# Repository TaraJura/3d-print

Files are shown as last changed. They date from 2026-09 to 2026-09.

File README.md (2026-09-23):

# 3D tisk a elektronika

Osobní projekt Jiřího Nováka: parametrické modely, 3D tisk, elektronika a zkušenosti ze sestavování. Znalosti i nové modely patří sem, aby šlo v další úloze pokračovat bez opakovaného vysvětlování. Nejde o firemní TechTools projekt ani o TechTools Brain.

Jiří popíše požadovaný díl nebo změnu běžným jazykem. Agent připraví model programově ve FreeCADu a Jiří si výsledek prohlédne.

[Sekce elektroniky](elektronika/README.md) je určená také pro všechny další osobní elektronické projekty bez vazby na 3D tisk. Nový projekt patří do `elektronika/<nazev>/` a do tamního indexu; jeho úplný propojený kontext zůstává v tomto repozitáři. Firmware existujícího autíčka má výjimku kvůli zachování původní cesty u modelu.

## Kde začít

- [AGENTS.md](AGENTS.md) — pravidla pro další práci agentů.
- [Tiskárna](docs/tiskarna.md) — Anycubic Kobra X, ověřené údaje a neznámé.
- [Software](docs/software.md) — FreeCAD, Anycubic Slicer Next a spuštění makra.
- [Sklad tiskových materiálů a profily](docs/materialy.md) — evidence filamentů, známé zůstatky, defaulty a doporučení.
- [Postup práce](docs/workflow.md) — od zadání přes model a slicer k vyhodnocení tisku.
- [Deník tisků](docs/denik-tisku.md) — skutečně hlášený průběh a výsledky.
- [Modely](models/README.md) — přehled všech dílů a jejich zdrojů.
- [Elektronika](elektronika/README.md) — zapojení, zkoušky a aktuální stav projektů.
- [Sklad elektroniky a vybavení](elektronika/vybaveni.md) — kanonický inventář včetně fyzicky převzaté sady kondenzátorů.

## Aktuální stav k 19. 9. 2026

**V3 25:1 po první a druhé várce, 20. 9. 2026:** připravená je [jedna kombinovaná podložka s26 kusy](models/auticko-silovy-prevod-25/rozlozeni/kombinovana-03-2026-09-20/README.md):13 dosud netištěných z původní03,7 náhrad první várky a6 druhé. Čepy i osa jsou nastojato; proces obsahuje ověřené skutečné podpory plošiny, osy a obou těhlic. **Použít tuto jednu podložku místo samostatné03 a sedmidílného dotisku.** Odhad19h37min /120,09g. Rám, víko objímky a úplnost obou motorových klínků čekají na upřesnění;26 není potvrzení kompletního použitelného inventáře. Tisk ani montáž této kombinace nejsou fyzicky ověřené.

**Doplnění 20. 9. 2026:** [celá V3 25:1 po revizi fitů](models/auticko-silovy-prevod-25/README.md) je připravená jako tiskový prototyp: 66 kusů na [třech podložkách 26 / 27 / 13](models/auticko-silovy-prevod-25/rozlozeni/README.md), včetně všech čtyř kol. Zachovává původní 20° ozubení a nové kluzné otvory 8,6 / 12,6; pevné spoje jsou oddělené podle funkce. Nominální CAD a exporty jsou ověřené pro tuto revizi; celý konzervativní radiální scénář zůstává nepokrytý, fyzická montáž a jízda neověřené. Další vzorky nejsou podmínkou předání. Soubory se předávají výhradně v projektu; na plochu se nic dalšího nekopíruje.

**Nahrané couvání, 23. 9. 2026:** verze `v3-reverse-v1` přidává **Držet pro couvání / ArrowDown**, opačnou polaritu motoru při stejném PWM 128/255 a zachovává servo 1275 / 1575 / 1875 µs při 50 Hz. **Je nahraná a potvrzená třemi pasivními výpisy; uživatel následně obecně potvrdil funkčnost („Hele, všechno to funguje“).** Překlad a úplné offline regrese prošly. Konflikt vpřed/vzad zastaví obě ovládání. Při odmítnuté rychlé změně směru je nutné pustit všechny ovladače a znovu stisknout; samotný čas ani opakovaný HOLD pohon neobnoví. Před opačným směrem je požadováno nejméně 250 ms skutečně vypnutého výstupu, což není měření zastavení motoru. Piny ani směr kol při couvání se nepřepojují/neobracejí. Upload **86 716 B / 22 stran / exit 0** a tři pasivní výpisy potvrdily novou verzi a klidové výstupy. Čítače zařízení byly stabilní **HTTP=29 / closed=29**; původ dřívějších požadavků není určený. Agent odeslal 0 sériových dat, 0 HTTP a 0 pohybových povelů; port je zavřený a volný. **Po následné zkoušce uživatel obecně potvrdil funkčnost; agent pohyb ani elektrické měření PWM neprováděl.** [Nová evidence uploadu](models/jednoduche-auticko/firmware/prvni-motor/evidence/2026-09-23-v3-reverse-v1-upload/README.md). Uživatel nově potvrdil servo odpojené v dotazu zahrnujícím UNO na USB a motor bez napájení. [První fyzická zkouška](elektronika/auticko/rizeni-v3.md#příští-zkouška-couvání--zatím-neprovedená) má nyní obecné uživatelské potvrzení funkčnosti.

**Historická kalibrace V3, 22. 9. 2026:** Dříve byl nahraný **`v3-steering-v4`: střed 1575 µs, zachované ±300 µs a 50 Hz (1275 / 1575 / 1875 µs)**. Upload **84 948 B / 21 stran / exit 0** a tři pasivní USB výpisy potvrdily novou verzi, klid motoru, `steeringUs=neutralUs=1575` a `rangeUs=300`. **Uživatel následně s připojeným táhlem a povelem Rovně potvrdil správnou neutrální polohu kol: „Super, takhle to je perfektní“.** Jde přímo o +50 µs od v3 ve směru Doprava, bez mezikroku 1550 µs. Uživatel na v3 s připojeným táhlem a povelem Rovně stále hlásil kola mírně doleva; první +25µs trim byl podle něj skoro neznatelný. Potvrzení se týká neutrální polohy při krátké zkoušce s koly nad stolem a motorem bez napájení; úhel, všechny dorazy, dlouhodobý provoz ani jízda nejsou ověřené. Pro upload v4 uživatel nově odpověděl „Ano“ na dotaz zahrnující odpojení servo plusu, ponechání UNO na USB a motor bez napájení. Táhlo zůstalo při závěrečné zkoušce připojené. Doporučené odpojení serva po tomto úspěchu tehdy nepotvrdil; nové potvrzení odpojení přišlo před uploadem couvání uvedeným výše. Akceptace neutrálu v4 se nepřenáší na nový hash. Potvrzený pohyb volného serva v2 oběma směry zůstává samostatným výsledkem. [Přesná chronologie](elektronika/auticko/kontrolni-zapojeni.md#hlasova-zkouska-22-9-2026), [řízení V3](elektronika/auticko/rizeni-v3.md) a [firmware s evidencí](models/jednoduche-auticko/firmware/prvni-motor/README.md) rozlišují verze, upload a fyzické výsledky. Přímý 6,35V zdroj zůstává rizikovým pokusem nad uváděnými 4,8–6 V, bez hotového regulátoru.

Tiskárna je **Anycubic Kobra X s tryskou 0,4 mm**. K dispozici je bílý a černý **Alzament PLA Basic 1,75 mm**. Uživatel potvrdil spuštění FreeCADu a Anycubic Slicer Next na Ubuntu 26.04.1 LTS.

První model je [polička na zárubeň 90 × 50 mm](models/policka-na-zaruben/README.md). Její geometrie byla ověřena a uživatel model otevřel i importoval do sliceru. Uživatel oznámil zahájení prvního tisku; **fyzický výsledek ani první vrstva zatím nejsou potvrzené**. U zkontrolovaného lokálního G-code není jednoznačně doloženo, že jde právě o úlohu běžící na tiskárně. Podrobnosti jsou v [deníku](docs/denik-tisku.md).

Další model je [jednoduché autíčko s jedním motorem](models/jednoduche-auticko/README.md): čtyři kola, společná zadní náprava a ozubený převod. První FCStd a jednotlivé STL jsou vytvořené a geometricky zkontrolované. **Uživatel na vytištěném vzorku zvolil otvor 2,2 mm a následně potvrdil dobré nasazení hotového [pastorku](models/jednoduche-auticko/stl/pastorek.stl).** Tisk zbývajících 13 kusů zadal s odhadem sliceru 3 h 15 min; dokončení zatím nepotvrdil. **První sekundový rozběh samostatného motoru tlačítkem z telefonu přes UNO R4 WiFi a L293D uživatel potvrdil.** [Záznam sestavování, zapojení a posledního stavu](elektronika/auticko/prvni-stolni-test.md) obsahuje i provizorní napájení a otevřené body. Fyzická montáž podvozku a jízda ještě ověřené nejsou.

Autíčko nově doplňuje **[snímatelná plošina s užitnou plochou 170 × 60 mm](models/jednoduche-auticko/strecha.md)**. Nasazuje se na čtyři existující výstupky u kol; původní rám se nemusí tisknout znovu. **Uživatel potvrdil dokončení tisku a nasazení.** Správný dosed, provozní vůle, nosnost a stabilita nejsou potvrzené.

[Elektronika autíčka](elektronika/auticko/README.md) soustřeďuje zapojení a historii motorových zkoušek. **Historická verze `hold-to-run-v2` byla přeložená, otestovaná a nahraná 19. 9.; dnešní upload V3 je uveden výše.** Předchozí požadavek na návrat k sekundovému pulzu uživatel odvolal před uploadem. [Firmwarový návod](models/jednoduche-auticko/firmware/prvni-motor/README.md) uvádí skutečný stav testů a nahrání. [Záznam potíží](elektronika/auticko/potize-po-montazi.md) odlišuje těžký rozjezd již na starém programu od přerušování při skutečném držení. Po návratu uživatel obnovil stránku a opakovaně potvrdil funkční držení, puštění a další stisk („Jo, funguje to, perfektní“). Jde o jeho fyzickou zkoušku v2, nikoli měření doběhu či zatížení. Nákup nářadí a baterií i použití silikonového oleje jsou v [inventáři](elektronika/vybaveni.md); vlastnictví neznamená potvrzené zapojení.

Dokončený je nový model [samostatného autíčka s převodovkou 12:1](models/auticko-s-prevodovkou/README.md), koly Ø80 a užitnou plošinou 170 × 60 mm pro stávající elektroniku. Vůči původnímu převodu 3:1 s koly Ø60 je ideální tažná síla 3× a rychlost 1/3, před ztrátami. [Balíček pro tisk](models/auticko-s-prevodovkou/tiskovy-balicek.zip) obsahuje 20 kusů ze 13 typů STL, každý soubor tisknout jednou. Hotové jsou parametrický FCStd, náhledy a montážní návod; prošly kontroly těles, STL, kolizí, soukolí i montážních vůlí. Původní modelové soubory zůstaly beze změny. Jiří nyní při fyzické zkoušce V2 hlásí opakované zasekávání a podezření na nesprávnou rozpěrku; příčina ani výsledek přestavby nejsou potvrzené. [Audit a návrh revize převodovky](models/auticko-s-prevodovkou/revize-prevodovky.md) ukázal potřebu změnit vedení os, axiální stohy a šířku záběru. Uživatel zvolil pouze tištěné mechanické díly. Samostatná silnější revize 25:1 je popsaná níže; původní CAD i firmware zůstávají zachované.

**Dokončená je třetí samostatná [varianta s předním zatáčením přes SG90](models/auticko-se-zatacenim/README.md).** Má převodovku 12:1, plošinu 170 × 60 mm a kola Ø76 × 12 mm se skutečným tištěným dezénem. CAD, exporty a geometrické kontroly jsou hotové; kompletní balíček obsahuje 33 kusů, přestavba z V2 vyžaduje 22 kusů při převzetí 11 původních. Pro Kobra X je připravené [rozložení na dvě podložky](models/auticko-se-zatacenim/rozlozeni/README.md), 31 + 2 kusy. Fyzický tisk, montáž, síla řízení a přilnavost zůstávají neověřené. Potvrzené servo a měření účinného poloměru páčky 15 mm jsou v [inventáři](elektronika/vybaveni.md). Oba předchozí modely i firmware zůstávají zachované; elektronika zatáčení je další etapa.

**Aktuální [V3 25:1 s řízením SG90](models/auticko-silovy-prevod-25/README.md)** má 34 typů / 66 tištěných kusů a samostatně archivovanou předkalibrační variantu. Kompletní ZIP a tři 3MF zahrnují čtyři kola a všechny opakované díly; počty se už nenásobí. Poslední 8mm pastorek zůstává v 12mm věnci při kontrolovaných axiálních posuvech s rezervou 1,5 mm. Rozměry konkrétní páčky, fit celé sestavy a jízda teprve čekají na fyzické ověření. Původní CAD a firmware jsou zachované.

## Jak zapisovat poznatky

U nového údaje uvést původ: zadání uživatele, fyzické měření, údaj výrobce, kontrola souboru, návrhová hodnota nebo doporučení. Zadané rozměry nejsou automaticky měřením skutečného předmětu. Doporučení není potvrzené nastavení a kontrola modelu není důkaz úspěšného výtisku.

Nové parametry a změny modelů zapisovat do příslušné složky modelu; elektroniku do `elektronika/<projekt>/`, elektronické vybavení do [inventáře](elektronika/vybaveni.md) a tiskové materiály do [skladu](docs/materialy.md). Po tisku doplnit deník podle skutečného výsledku. **Vytvoření STL, úspěšné řezání ani odeslání úlohy nestačí k označení tisku za úspěšný.** Upload programu sám není potvrzením fyzického výsledku.

## Projekt a Git

Aktuální místní checkout je `/home/novakj/3d-print`; osobní repozitář je [TaraJura/3d-print](https://github.com/TaraJura/3d-print). Git příkazy spouštět v tomto checkoutu: domovský adresář `/home/novakj` má vlastní, odlišný repozitář. Zdejší obsah se přípravou dokumentace automaticky necommituje ani nepublikuje.

Malé záměrné soubory FCStd, STL a PNG patří k modelu a jsou verzovatelné. Instalátory, runtime, přístupové údaje, cache a automatické zálohy do projektu nepatří. Původní kopie poličky v `Documents/3D-models` zůstala zachovaná kvůli otevřeným souborům; další práci ukládat sem.

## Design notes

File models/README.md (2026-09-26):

# Modely

Každý model má vlastní složku se zadáním, editovatelným zdrojem, STL, skutečným CAD náhledem a výsledky kontrol. Nové modely ukládat sem. Zapojení a elektronické zkoušky patří do [elektroniky](../elektronika/README.md); potvrzené součástky a pomůcky do [inventáře](../elektronika/vybaveni.md).

| Model | Obsah a stav |
|---|---|
| [Zaoblený kryt trubky digestoře](kryt-trubky-digestore/README.md) | Předběžný půlkruhový kryt 150 × 75 × 98 mm pro přibližnou trubku Ø130: FreeCAD, STL, skutečné náhledy a jedna nařezaná 3MF podložka pro Kobra X. Dosednutí, odstup od zdi, provozní teplota, vhodnost PLA a tisk čekají na fyzické ověření. |
| [Koupelnová přepážka B](koupelnova-prepazka/revize-03-575-zacvak/README.md) | Návrh k posouzení: 575 × max. 20 × cca 10 mm po montáži, 3 TPU díly 8 mm + lože 2 mm, mechanické zacvaknutí bez lepidla mezi díly. CAD, náhledy a oba experimentální TPU projekty ověřeny počítačově; fyzické zacvaknutí, přilnutí a těsnost neověřeny |
| [Polička na zárubeň](policka-na-zaruben/README.md) | Deska 90 × 50 mm; geometrie ověřena; uživatel zahájil první tisk, fyzický výsledek nepotvrzen |
| [Jednoduché autíčko](jednoduche-auticko/README.md) | Pastorek s CAD otvorem Ø 2,2 mm vytištěn a nasazení potvrzeno; tisk dalších 13 kusů zadán. [První sekundový stolní test motoru přes telefon](../elektronika/auticko/prvni-stolni-test.md) potvrzen uživatelem; montáž podvozku a jízda neověřeny |
| [Snímatelná plošina autíčka](jednoduche-auticko/strecha.md) | Jeden přídavný díl na existující výstupky, rovná užitná plocha 170 × 60 mm. Dokončení tisku potvrdil uživatel; fyzický fit a nosnost teprve čekají na ověření |
| [Robotická ruka na autíčko](roboticka-ruka/README.md) | První lehký prototyp s krokovým otáčením základny, ručně polohovatelným ramenem a otevřenou dvouprstou koncovkou; FreeCAD, STL, náhledy a dvě nastavené a místně nařezané 3MF podložky hotové. Fyzický tisk, fit a nosnost neověřené |
| [Držák toaletního papíru s čelním šuplíkem](drzak-toaletniho-papiru-s-prihradkou/README.md) | Vlastní parametrický návrh podle fotografie bez měřítka: pevný strop, volně výsuvný šuplík, dvě ramena, osa a zátka. CAD, STL a [dvě nastavené a místně nařezané 3MF podložky](drzak-toaletniho-papiru-s-prihradkou/rozlozeni/README.md) pro Kobra X; tisk, hladký chod a kotvení neověřené. |
| [Nové autíčko s převodovkou 12:1](auticko-s-prevodovkou/README.md) | Samostatný nový prototyp s koly Ø80 a užitnou plošinou 170 × 60 mm. FCStd, náhledy, návod a [ZIP 20 kusů](auticko-s-prevodovkou/tiskovy-balicek.zip) hotové; geometrické kontroly prošly. Nově uživatel hlásí fyzické zasekávání; [audit a návrh revize](auticko-s-prevodovkou/revize-prevodovky.md) hotový, příčina nepotvrzená a původní geometrie zachovaná |
| [Autíčko s předním zatáčením](auticko-se-zatacenim/README.md) | Třetí samostatný CAD prototyp: pohon 12:1, plošina 170 × 60 mm, SG90 a kola Ø76 × 12 mm s dezénem. Kontroly, FCStd, náhledy a balíčky 33 / 22 kusů hotové. [Rozložené 3MF pro Kobra X](auticko-se-zatacenim/rozlozeni/README.md): 31 + 2 kusy. Tisk, fyzická montáž a řízení zatím nepotvrzené |
| [Revidovaná V3 s převodem 25:1](auticko-silovy-prevod-25/README.md) | **Tiskový prototyp po revizi 20. 9.: 34 typů / 66 kusů, čtyři kola, [tři 3MF 26 + 27 + 13](auticko-silovy-prevod-25/rozlozeni/README.md).** Původní 20° ozubení, kluzné otvory 8,6 / 12,6 a samostatné pevné spoje. Nominální CAD a exporty ověřené; plný konzervativní radiální scénář neprošel, skutečný fit a jízda neověřené. Další vzorky nejsou podmínkou předání. |

Společný [postup práce](../docs/workflow.md) a [deník tisků](../docs/denik-tisku.md) doplňují konkrétní poznámky modelu.

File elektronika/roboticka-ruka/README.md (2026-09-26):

# Robotická ruka na autíčku — elektronika

Projekt založen 23. 9. 2026 pro první lehký tisknutelný prototyp paže na jednoduchém kolovém autíčku. Mechanický model a tiskové soubory jsou v [modelu robotické ruky](../../models/roboticka-ruka/README.md); stav zásob je pouze v [kanonickém inventáři](../vybaveni.md).

## Aktuální stav

- Jiří potvrdil dostupný krokový motor se štítkem hlasem čteným jako „StepMotor 28BY…-48, 5 V DC“. Přesné znaky označení, počet kusů, rozměry a funkce jeho motoru zatím nejsou fyzicky ověřené.
- První návrh využije krokový motor jen pro pomalé otáčení základny kolem svislé osy. Rameno a loket zůstanou ručně polohovatelné a otevřená dvouprstá koncovka nebude zatím aktivně svírat.
- Servo SG90 je v dosavadní evidenci určené pro řízení autíčka; s volným kusem pro paži se nepočítá.
- Pro tuto paži zatím není potvrzené elektrické zapojení, zdroj napájení, přiřazení pinů, firmware, nahrání programu ani fyzická zkouška pohybu.

## Podklady pro navazující zapojení

[LaskaKit uvádí pro běžný 28BYJ-48](https://www.laskakit.cz/krokovy-motor-28byj-48/) napájení 5 V DC, pět vodičů a kompatibilitu s řadičem ULN2003. [Katalog sady MAXI RFID](https://www.laskakit.cz/laskkit-arduino-maxi-starter-kit--rfid/) obsahuje jeden 28BYJ-48 a jeden ULN2003. Katalog není ověřením, že konkrétní řadič Jiří fyzicky převzal nebo že jeho motor je přesně tato varianta. Výrobce také upozorňuje na vůli plastové převodovky; přesnou polohu ani nosnost paže z katalogu neodvozujeme.

Před první elektrickou zkouškou určit štítek a konektor skutečného motoru, ověřit dostupnost odpovídajícího řadiče a regulovaného 5V zdroje, proměřit polaritu a napětí zdroje bez motoru a vybrat volné piny řídicí desky podle [aktuálního zapojení autíčka](../auticko/README.md). Motor se nemá připojovat přímo na výstupy Arduina. Napájení a společnou zem řadiče a řídicí desky zakreslit až pro konkrétní fyzické zapojení.

Zkoušky a jejich výsledky sem zapisovat odděleně od mechanického fitu a od pouhého překladu programu.

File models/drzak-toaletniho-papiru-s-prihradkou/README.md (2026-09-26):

# Držák toaletního papíru s čelním šuplíkem

Tiskový **prototyp** podle fotografie „Compartment Toilet Paper Holder“, kterou Jiří poslal 24. 9. 2026. Fotografie nemá měřítko ani technické rozměry. Černý obdélník na horní ploše je samostatný telefon. Tento vlastní návrh má pevnou horní odkládací plochu, lehce výsuvný šuplík s integrovaným úchopem a dvě boční ramena pro roli. Všechny rozměry níže jsou návrhové, nikoli změřené z předlohy.

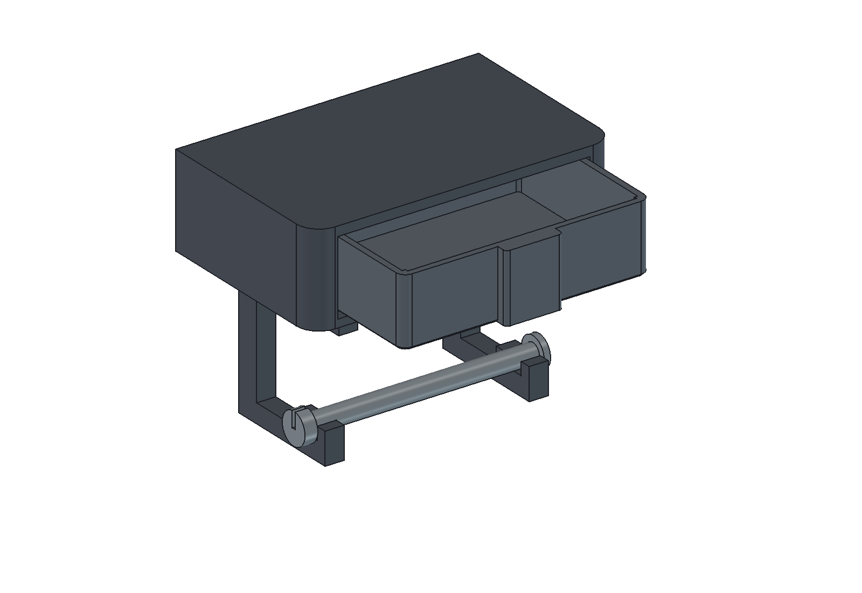
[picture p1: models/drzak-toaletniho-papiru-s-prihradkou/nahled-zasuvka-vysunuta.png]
Šuplík částečně vysunutý v sestavě


## Soubory k použití

- [Parametrický FreeCAD model](drzak.FCStd), [zdrojové makro](drzak.FCMacro), [CAD sestava](nahled-sestava.png), [CAD náhled s ilustrační rolí](nahled-s-roli.png) a [měření/validace modelu](kontrola-modelu.json).
- [Podložka 01 – schránka a dvě ramena](rozlozeni/drzak-podlozka-01-nastaveny-projekt.3mf): tři fyzické kusy.
- [Podložka 02 – šuplík, osa a pojistná zátka](rozlozeni/drzak-podlozka-02-nastaveny-projekt.3mf): tři fyzické kusy.
- [Přehled podložek, očíslované náhledy a proces](rozlozeni/README.md). Každou `.3mf` podložku otevři samostatně **jako celý projekt**, jednou, bez ručního přerovnávání nebo množení.
- [Pět STL typů](stl/) pro případné další úpravy; `bracket.stl` je v připraveném projektu 2×.

Původní návrh s odnímatelným víkem je výslovně označený jako [historická varianta](historie/prvni-navrh-s-vikem/README.md). Pro aktuální sestavu použij jen soubory z této složky a jejích `stl/` a `rozlozeni/`.

## Návrhové rozměry a vůle

| Věc | Návrhová hodnota | Fyzická zkouška |
|---|---:|---|
| Schránka vně | 190 × 120 × 58 mm | prostor u stěny |
| Pevná horní deska | 6 mm | průhyb při odložení telefonu |
| Čelní otvor | 158 × 47 mm | stav hran po tisku |
| Šuplík vně, bez úchopu | 155,6 × 114 × 43 mm | volný chod po tisku |
| Užitný prostor šuplíku, bez zaoblení | přibližně 147,6 × 106 × 39 mm | zda vyhovuje ukládaným věcem |
| Boční vůle | **1,2 mm na každé straně** | změnit podle skutečného tisku |
| Vůle pod stropem | **1,2 mm** při vyrovnané poloze modelu | zda čelo nedrhne |
| Montážní svislá vůle nad lištami | **0,8 mm** v nezatížené CAD poloze | vlastní tíha usadí dno na lišty; ověřit klouzání |
| Vodítka | 2× lišta široká 5 mm, vysoká 2 mm | očistit případné přetoky vrstev |
| Vzdálenost vnitřních ploch ramen | 116 mm | role široká nejvýše 112 mm |
| Prostor role | návrh pro roli do Ø120 mm; náhled Ø110 × 110 mm | skutečný rozměr role |
| Osa / dutinka role | osa jmenovitě Ø12 mm; dutinka nejméně Ø13 mm | volný běh konkrétní role |
| Otvory do stěny | 130 mm vodorovně, Ø5,5 mm | podklad, vruty a kotvy |

Boční vůli lze snadno měnit v tabulce `Parameters` v FCStd položkou **SlideClearance** (výchozí 1,2 mm). Odvodí se z ní šířka šuplíku a montážní poloha, takže se drží stejná vůle vlevo i vpravo. `RailGap` je samostatná výchozí hodnota 0,8 mm pro volné zavedení a toleranci vrstvy; při vložených věcech se šuplík opře o úzké lišty. Ve FreeCADu jsou lišty v příčných intervalech x = 19–24 a 166–171 mm, dno šuplíku sahá od x = 17,2 do 172,8 mm; na jeho spodní ploše tedy zbývá 1,8 mm od každé boční hrany k nejbližší liště. Lišty míjejí zahloubení šroubů M4 nejméně o 2,4 mm. Mají zaoblené čelní konce a zadní spodní hrana zásuvky je sražena 1,5 mm. Vodítka mají omezenou kontaktní plochu; mechanismus nemá tuhou západku.

Šuplík se dá **celý vytáhnout** směrem dopředu. To je úmyslný způsob úplného vyjmutí pro čištění a pro přístup ke šroubům, takže při vysunutí nadoraz je třeba jej držet rukou. Ve FreeCAD sestavě byly změřeny nominální mezery 1,2 mm vlevo/vpravo a nahoře, 0,8 mm nad lištami a 1,0 mm za zadní hranou. Průnik schránky se šuplíkem je 0 mm³ v zavřené poloze i při posunech 25, 50, 75, 100 a 114 mm; podrobnosti jsou v `kontrola-modelu.json`. Stejná kontrola bez průniku prošla i po snížení šuplíku o 0,8 mm na pracovní dosednutí k lištám. **Skutečný lehký chod a potřebná korekce vůle lze potvrdit až po fyzickém tisku.** Při změně `SlideClearance` se přepočítá šuplík, ale tvar schránky zůstane stejný; po prvním výtisku proto případná oprava boční vůle vyžaduje novou podložku pouze pro upravený šuplík, nikoli nový tisk velké schránky.

## Kusovník a montáž

Tisknout **1× schránku, 1× šuplík, 2× stejné rameno, 1× osu, 1× zátku** = šest kusů. Veškeré rozměry šroubů jsou návrhové: pro ramena **4× M4 × 25 mm se zápustnou hlavou do 9 mm**, odpovídající matice a podložky. Skrz dno schránky a horní pásy ramen jsou otvory Ø4,6 mm; hlavy zapadnou do kuželových zahloubení v horní ploše dna a nezachytávají šuplík. Vlož šrouby **zevnitř schránky dolů**, matice s podložkami utáhni pod rameny. Pro upevnění na stěnu počítej se **2× vrutem přibližně Ø5 mm se zápustnou hlavou do 11 mm** a hmoždinkami zvolenými podle skutečného podkladu. Jejich délka, druh stěny ani nosnost kotvení nejsou známy z fotografie. Hlavy jsou zapuštěné v zadní stěně a po vyjmutí šuplíku přístupné přímo čelním otvorem.

1. Vyndej šuplík. Ve schránce nasaď obě ramena čtyřmi M4; jejich ploché horní pásy patří pod dno a otevřená lůžka osy proti sobě. Zkontroluj, že hlavy šroubů sedí pod rovinou dna.
2. Na vhodné pevné stěně vyznač dva body 130 mm vodorovně, ověř podklad a zvol odpovídající kotvy. Schránku upevni přes zadní zápustné otvory. Před vrtáním ověř skryté vedení; obklad vyžaduje postup pro jeho materiál.
3. Zasuň prázdný šuplík zepředu. Náběhovou hranou jej veď mezi boční stěny na dvě úzké lišty. Zkus celý pohyb rukou a případné drobné otřepy po tisku začisti. Nenuť jej silou do těsného vedení.
4. Nasuň roli na osu, polož ji do obou otevřených lůžek a nasaď pružnou zátku na volný konec za pravým ramenem. Při výměně role zátku sejmout a osu vyjmout.

Střed osy je 73 mm pod dnem schránky; ideální role Ø120 mm má od dna přibližně 13 mm. Pružná zátka má návrhovou vůli; její odpor a bezpečné držení je třeba ověřit rukou. Širší nebo jumbo roli model před tiskem uprav v parametrech a znovu zkontroluj související délku osy a polohy ramen.

## Tisk, pevnost a stav ověření

Schránka je na STL položena **zadní stěnou na podložku** a její čelní dutina je při tisku otevřená nahoru. Skrytá zadní hrana je rovná v celé šířce 190 mm, aby první vrstvy měly plnou oporu; pohledové přední rohy zůstávají zaoblené. Pevný strop tak nevytváří dlouhý nepodepřený most. Šuplík se tiskne dnem dolů, včetně úchopu od první vrstvy. Ramena se tisknou **naplocho na boční ploše**, aby obrys nosného pásu a stojiny ležel v rovině vrstev. Pro orientační kontrolu spodního pásu 12 × 12 mm: při předpokládaných 10 N na jediném rameni a délce 61 mm vychází prostým nosníkovým vzorcem asi 2,1 MPa nominálního ohybového napětí. Tento výpočet neověřuje spoje, vrstvy, šrouby, vytržení ze stěny ani sílu při trhání papíru.

FreeCAD potvrdil pět platných jednodílných tvarů a uzavřená STL. Uložený FCStd se znovu otevřel a přepočítal při změně šířky těla 190 → 194 → 190 mm a boční vůle 1,2 → 1,6 → 1,2 mm. Další ověření tiskových projektů a vrstev je v [README podložek](rozlozeni/README.md). **Skutečný tisk, montáž, plynulý chod šuplíku, pasování zátky a role, zatížení horní plochy ani kotvení ke konkrétní stěně nejsou fyzicky ověřené.** Odložení jednoho běžného telefonu asi do 250 g v klidu je pouze návrhový předpoklad, nikoli ověřená nosnost. PLA nevystavuj přímému ostřiku ani dlouhodobému horku.

[drzak.FCMacro](drzak.FCMacro) přepisuje FCStd, pět STL a kontrolní JSON. Při změně parametrů přímo v FCStd slaď také zdrojové hodnoty v makru; pak obnov STL, CAD náhledy a obě 3MF podložky. [nahled.FCMacro](nahled.FCMacro) vytváří tři CAD PNG a ukládá viditelnou sestavu. Generátory tiskových podložek jsou ve složce `rozlozeni/`.

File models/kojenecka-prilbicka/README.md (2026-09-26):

# Přilbička — vizuální koncept

**Aktuální vzhledová varianta:** [v2 — římská velitelská přilba](v2/perspektiva-cad.png), také [zepředu](v2/zepredu-cad.png). Jiří chtěl výraznější, „epický“ generálský vzhled. V2 má červený chochol, bronzovou kupoli, zlacený čelní pás s vavřínem a stylizovaným orlem, zaoblenější lícnice a zadní štít. [Generovaný obrázek](v2/stylova-predloha.png) je pouze stylová předloha ([zadání imagegen](v2/stylova-predloha-prompt.md)); oba soubory `*-cad.png` jsou skutečný náhled odlišné CAD geometrie.

**Stav:** jen ilustrativní náhled. CAD obsahuje otevřené plochy a křivky bez objemu či definovaného nositelného střihu. Není určen pro výrobu, nasazení na dítě ani ochranu hlavy. STL, 3MF a tiskové podložky nebyly vytvořeny: Jiří zatím požádal pouze o vizualizaci k úpravám.

## Zadání a jeho meze

- Jiří uvedl věk dítěte 3 měsíce, šířku hlavy 125 mm a výšku 150 mm. Jde o jeho údaj, nikoli o naše ověřené měření.
- Zvukový přepis požadavku na větší prostor uvnitř není jednoznačný. Širší boční proporce obrázku jsou jen výtvarný návrh; nepředstavují bezpečnou vůli ani anatomický tvar.
- Chybí kompletní tvar hlavy, obvod, poloha uší a čela, účel nošení a klinické posouzení. Dvě uvedené míry nemohou určit bezpečně padnoucí helmu pro kojence.

## Aktuální soubory a kontrola

- `v2/velitelska-prilba.FCMacro` vytváří `v2/velitelska-prilba.FCStd` a dva náhledy přímo ve FreeCADu. Opakované spuštění tyto tři výstupy přepíše.
- Kontrola po sestavení v2: 29 CAD objektů, 0 plných těles a 0 neplatných tvarů; oba výsledné PNG byly otevřeny a vizuálně zkontrolovány. Nejde o kontrolu fitu, materiálu ani bezpečnosti.

## Původní varianta v1

- `koncept.FCMacro` vytvoří otevřenou CAD plochu, uloží `koncept.FCStd` a v GUI pořídí dva PNG náhledy přímo z geometrie FreeCADu. Při opakovaném spuštění tyto tři výstupy přepíše. Rozměry v makru jsou výhradně ilustrativní měřítko a neslouží pro fit.
- `koncept-perspektiva.png` a `koncept-zepredu.png` jsou starší vzhledové náhledy.
- Kontrola v makru vyžaduje nula plných těles.

Pokud má jít o léčebnou kraniální ortézu, musí indikaci a tvar posoudit pediatr a specialista na individuální měření a nasazení. Běžná pokrývka hlavy pro spánek je také samostatná bezpečnostní otázka.

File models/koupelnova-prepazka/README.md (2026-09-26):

# Koupelnová přepážka B

**Nový návrh k posouzení: [revize 03 — 575 mm se zacvakávacími spoji](revize-03-575-zacvak/README.md).** Tři díly, 8 mm TPU + 2 mm lože; bez lepidla mezi díly. CAD a tiskové projekty jsou ověřené počítačově, fyzické zacvaknutí a těsnost zatím ne.

**Předchozí varianta je [revize 02 — 8mm TPU + 2mm lože](revize-02-8mm/README.md); soubory přímo v této kořenové složce zůstávají starou 10mm referencí a nejsou aktuálním předáním.**

**22. 9. večer: Jiří nahlásil neúspěšný fyzický tisk.** [Diagnostika a zachované důkazy](diagnostika/2026-09-22-nepovedeny-tisk/README.md) rozlišují nalezený místní PLA export od připraveného TPU projektu; skutečně spuštěný soubor ještě není potvrzený. Pro ověření nastavení otevřít celý [tehdejší testovací projekt revize 02](revize-02-8mm/rozlozeni/TEST-EXPERIMENT-spoj-Alzament-TPU95A.3mf), nikoli kopírovat staré díly do jiného procesu. Následující text a soubory této kořenové složky jsou historický popis 10mm reference.

Parametrický mechanický návrh, 22. 9. 2026. Účel: **zabránit vytékání/průtoku vody**. Geometrie prošla kontrolou; fyzická těsnost, spoj, přilnutí a tisk zatím ověřené nejsou.

**Otevřená montážní revize:** Jiří nyní upřesnil limit 10 mm pro celou nalepenou instalaci. Současný CAD má samotný výtisk vysoký 10 mm, takže neponechává místo pro lepicí lože. Je to geometricky ověřená reference, nikoli finální montážní/tisková revize. Výška výtisku a spojové vůle budou upravené po volbě doloženého lepicího postupu.

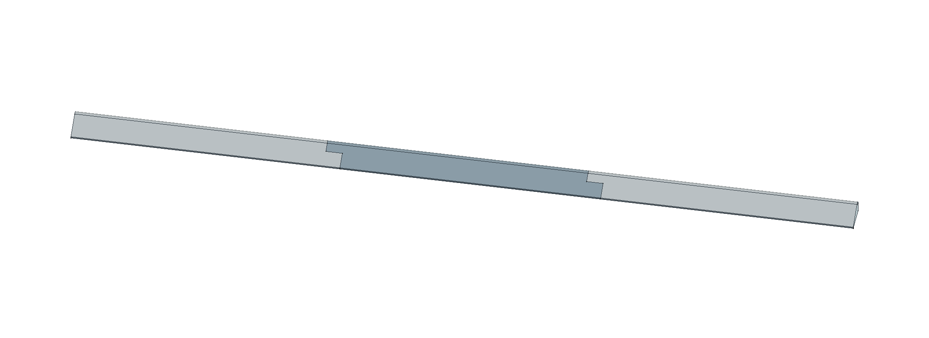
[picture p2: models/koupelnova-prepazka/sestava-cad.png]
Sestava ze skutečného CAD


## Potvrzené zadání

- Jiří zvolil asymetrický náběhový profil **B** z [orientačního srovnání](navrhy/README.md).
- Celková délka sestavy **570 mm**, uživatelské měření.
- Šířka **nejvýše 20 mm** včetně spojů a všech výstupků. Nominální CAD má 20 mm, fyzická rozměrová tolerance není ověřená. Do limitu se nesmí dodatečně přidat boční patka či vůle.
- Původně nejvyšší bod profilu **10 mm**; následně výslovně zpřesněno jako maximum celé nalepené instalace. Současná reference ještě neobsahuje montážní lože.
- Více napojovaných dílů kvůli ploše tiskové desky.
- TPU; dostupný vyzvednutý výrobek **Alzament TPU 95A 1 kg Gray**. 95A je katalogová tvrdost. Nasazení cívky ve stroji nepotvrzené. Kanonická evidence a zdroje jsou v [materiálech](../../docs/materialy.md).
- Podklad je dle Jiřího **jedna dlouhá kachlička bez spár pod lištou**. Druh glazury, rovinnost a lepení neměřeny/nevybrány.

Historie: dříve zadaná šířka 40 mm byla výslovně nahrazena limitem 20 mm ještě před finální geometrií. Nejasnost o „protékání“ byla opravena na zabránění vytékání. Původní ImageGen srovnání zůstává jen historickou vizualizací bez měřítka; aktuální PNG zde vycházejí ze skutečné CAD geometrie.

## Navržené rozdělení a spoj

Tři díly jsou **návrhová volba**, nikoli uživatelem zadaný počet. Oba spoje mají navržený podélný přesah **12 mm** a dělení v polovině šířky, tj. **10 mm**. Jde o boční stupňovité přeplátování: v přesahu leží dvě doplňující se poloviny vedle sebe. Nevzniká výstupek mimo šířku 20 mm ani horní lalok visící nad podložkou.

| Díl / STL | Délka výtisku | Rozsah X v sestavě | Počet |
|---|---:|---:|---:|
| [Díl 1](stl/dil-1.stl) | 196 mm | 0–196 mm | 1 |
| [Díl 2](stl/dil-2.stl) | 202 mm | 184–386 mm | 1 |
| [Díl 3](stl/dil-3.stl) | 196 mm | 374–570 mm | 1 |

Sestavená délka: **196 + 202 + 196 − 12 − 12 = 570 mm**. Každý díl má maximálně 20 × 10 mm v průřezu a rovný dosed v Z=0. STL mají místní počátek na minimu svého ohraničení.

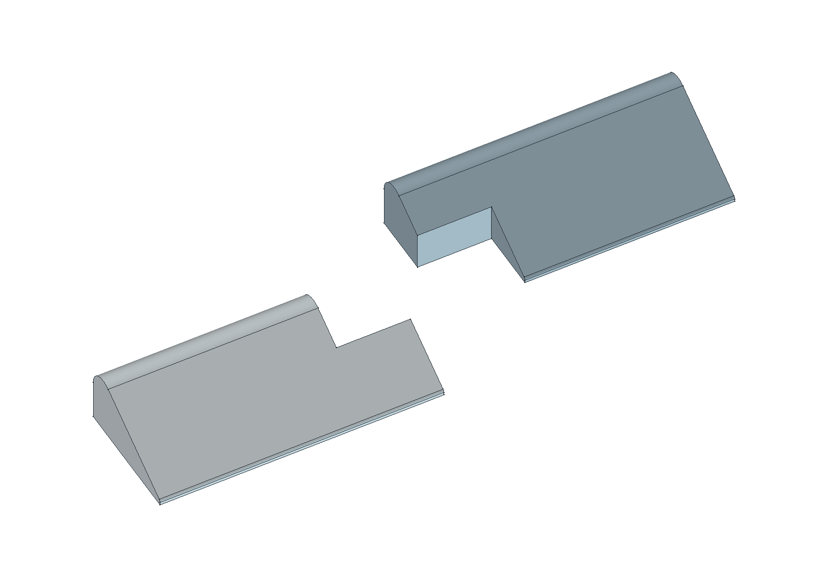
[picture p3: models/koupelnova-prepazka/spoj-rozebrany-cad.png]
Rozebraný spoj ze skutečné geometrie


Detail ukazuje výřezy skutečných konců dílů 1 a 2; pravý protikus je pouze pro přehlednost odsunut o 18 mm podélně, 9 mm do strany a 6 mm nahoru. Tyto posuny nejsou vůle ani montážní rozměry.

**Nominální vůle je 0 mm**, jako geometrický referenční styk. Spoj nemá západku ani jiný mechanický zámek; díly se bez upevnění mohou rozjet. Suchý styk a delší styčná čára nezaručují těsnost. Výrobní vůli, případné odlehčení vnitřních rohů a odolnost proti natržení je nutné ověřit na vzorku ze skutečného TPU. Rozměry celého výtisku je třeba změřit před montáží, zejména limit šířky 20 mm.

Další návrhové hodnoty: poloměr nízkého náběhu 0,5 mm a vysokého ramene 3 mm. Mezi rameny je společná přímá tečna, vespod souvislá plochá základna. Nejde o změřený profil původního silikonu.

## Upevnění a utěsnění — dosud neověřený návrh

Na uživatelem popsané kachličce bez spár navrhujeme souvislou tenkou pružnou lepicí/těsnicí vrstvu pod celou patou, utěsnění obou stupňovitých styků a zakončení lišty. Konkrétní prostředek musí prokázat přilnavost k tomuto TPU i glazuře a vhodnost pro mokré prostředí; zatím nebyl vybraný, koupený ani aplikovaný. Vzorek má ověřit přilnutí, případné odlepení a únik vody. Ani plná výplň výtisku sama o sobě nezaručuje nepropustnost.

CAD neobsahuje tloušťku montážního lepidla, toleranci povrchu ani těsnicí hmotu. Případná montážní vrstva zvětší výslednou instalační výšku nad 10 mm; pokud je 10 mm limitem celé instalace, je nutné ji zahrnout do další revize profilu. Způsob napojení konců na okolí zatím není známý.

## Soubory a přepočet

- [prepazka-B.FCStd](prepazka-B.FCStd): editovatelný model se standardní tabulkou, plně zavazbeným skicářem, extruzí, válci a booleovskými operacemi. Nevyžaduje vlastní Python třídu.
- [prepazka.FCMacro](prepazka.FCMacro): zdroj a regenerace FCStd, tří STL a geometrického kontrolního JSON. Hodnoty v `VALUES`; výstup je vedle makra. Existující soubory stejných názvů přepisuje.
- [nahled.FCMacro](nahled.FCMacro): skutečné GUI rendery; skryje pomocné tvary a uloží dokument s viditelnými díly 1–3. Dočasné výřezy a odsunutí neukládá do konstrukce.
- [Detail profilu](profil-B-cad.png): krátký výřez aktuálního profilu, bez změny geometrie.
- [Kontrola CAD](kontrola-modelu.json): rozměry, tělesa, kontakty, kolize, parametrické změny, STL a znovuotevření.
- [Historické podložky a tiskový stav](revize-02-8mm/historie/reference-10mm/rozlozeni/README.md): samostatné projekty; geometry-only varianta neobsahuje proces ani filament.

Makra spouštět skutečným FreeCADem podle [projektového postupu](../../docs/software.md#spuštění-makra-ve-freecadu). Tabulka FCStd dovoluje následný nativní přepočet; změny v ní je třeba promítnout i do `VALUES` a znovu exportovat STL, podložky a náhledy. Před regenerací uložit případné ruční změny. Parametry neměnit mimo použitelné geometrické rozsahy bez nové kontroly.

## Výsledky geometrické kontroly

- Sestava **570 × 20 × 10 mm** (odchylka nejvýše přibližně 1e−12 mm z numeriky CAD).
- **3 platná tělesa**, každé jeden solid; vzájemný průnik objemů 0 mm³.
- Sjednocení přesně vyplní souvislý profil: chybějící i přebytečný objem 0 mm³; sjednocený referenční solid má cca 70 323,972 mm³.
- Nominální vzdálenost protikusů 0 mm, styčná plocha každého spoje cca 201,052 mm². Plocha spodního dosedu každého dílu 3 800 mm².
- Tři uzavřené STL. Oblé plochy jsou teselované: maximální výška mesh je cca 9,999418 mm, tj. o 0,000582 mm nižší než přesný CAD; měřítko je 1:1.
- Dva testy změny rozměrů/přesahu/poloměrů prošly, pak byly obnoveny zadané hodnoty. Uložený FCStd byl znovu otevřen a přepočten; samostatně byla ověřena změna délky 570 → 600 → 570 mm bez spuštění generačního makra.

Jde o kontrolu počítačové geometrie. Fyzický fit, lepení, těsnost a rozměr výtisku zatím nikdo nepotvrdil. Tiskárna nebyla ovládána.

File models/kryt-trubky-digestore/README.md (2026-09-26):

# Zaoblený kryt trubky digestoře – první návrh

**Stav 26. 9. 2026:** předběžný parametrický návrh a místně nařezaná tisková podložka. Počítačově ověřená geometrie neprokazuje nasazení na konkrétní potrubí, vhodnost materiálu ani výsledek tisku. Nic nebylo odesláno tiskárně.

## Zadání a interpretace

Jiří chce zakrýt **viditelný svislý úsek trubky mezi horní plochou kuchyňské skříňky a sádrokartonem**. Trubka dále prochází skříňkami a stropem. Zadní strana krytu má zůstat otevřená ke zdi. Původní [ruční náčrt](podklady/nacrt-od-jiriho.png) byl hranatý; následně požádal o plynule kulatý vzhled.

| Údaj | Hodnota | Původ a význam |
|---|---:|---|
| Šířka krytu napříč trubkou | 150 mm | Jiří zadal 15 cm; výklad osy pro tento návrh |
| Výška krytu | 98 mm | Jiří zadal 9,8 cm pro přibližně 100mm mezeru |
| Průměr trubky | přibližně 130 mm | Jiří uvedl 13 cm, zatím bez měření |
| Zadní dosah boků | přibližně 70 mm | Jiří řekl „třeba 7 cm“ |
| Skutečná hloubka kruhového návrhu | **75 mm** | Návrhový poloměr při šířce 150 mm; o 5 mm více než odhad boků |
| Tloušťka stěny | 3 mm | Návrhová hodnota, nikoli zadaný rozměr |

Jeden díl tvoří **přední půlkruhový plášť**. Je otevřený vzadu, nahoře i dole, takže se může nasunout zepředu kolem stávajícího svislého potrubí; spodní zakřivená hrana má stát na skříňce. Boky zaoblení tvoří zadní ramena. Kryt nemá kotevní prvky ani tvrzenou stabilitu.

Při ideálně soustředné kruhové trubce Ø130 mm vychází vnitřní poloměr krytu **72 mm** a nominální radiální vůle **7 mm**. To je výpočet z přibližného zadání. Poloha trubky vůči zdi a skříňce není známa, proto ani soustřednost nelze předpokládat jako skutečnost. Půlkryt sahá dozadu jen k rovině středu kruhu; nemusí dosáhnout ke zdi ani skrýt pohled ze strany.

## Co je potřeba na místě ověřit

Před fyzickým tiskem nebo nasazením změřit:

1. **Nejmenší skutečnou světlou výšku** od skříňky po sádrokarton na celé šířce a hloubce krytu. Nominálních 98 mm ponechává proti odhadovaným 100 mm jen 2 mm.
2. **Největší vnější průměr** viditelného potrubí včetně spojů, límců, izolace a nerovností; zda je potrubí opravdu kruhové a svislé.
3. **Vzdálenost osy potrubí od zadní stěny a od přední hrany skříňky**, volný prostor před potrubím a zamýšlený pohled z boku. Z toho plyne potřebná hloubka krytu a reálný dosed otevřených ramen.
4. Zda má kryt pouze stát, nebo být bezpečně upevněný, a zda mu nepřekážejí dvířka či jiný díl kuchyně.
5. **Teplotu u potrubí při běžícím odsávání a vaření.** PLA v připraveném 3MF je jen dostupný návrhový tiskový profil; jeho vhodnost a bezpečnost v tomto místě nejsou potvrzené. Pokud místní teplota či požadavky instalace PLA vylučují, je nutné materiál a proces znovu zvolit a nařezat.

## Soubory a kontrola

- [Editovatelný FreeCAD dokument](kryt.FCStd) obsahuje tabulku `Parameters`, běžné objekty `Part` a výrazy; přepočet nevyžaduje vlastní Python třídu.
- [Zdrojové makro](kryt.FCMacro) vytváří FCStd, [STL](stl/kryt.stl) a [kontrolu modelu](kontrola-modelu.json). **Při opětovném spuštění tyto soubory přepíše**; před regenerací nejdřív slaď případné ruční změny ve FCStd s makrem.
- [Makro náhledů](nahled.FCMacro) vytváří [šikmý pohled](nahled-zaobleny-kryt.png) a [pohled shora](nahled-shora.png) ze skutečné CAD geometrie. Také ukládá FCStd pouze se zobrazeným finálním dílem.
- [Jedna připravená podložka](rozlozeni/README.md) obsahuje přesně jeden fyzický kus, očíslovaný náhled, variantu pouze s geometrií i místně nařezaný projekt pro Anycubic Kobra X 0,4 mm.

FreeCAD potvrdil platný **jeden solid** s hranicemi **150 × 75 × 98 mm**. STL je uzavřená manifold síť s 396 trojúhelníky, bez degenerovaných trojúhelníků; odpovídá měřítku 1:1. Uložený FCStd byl znovu otevřen a přepočten při zkušební změně šířky, výšky, hloubky a tloušťky, pak vrácen na výchozí hodnoty. Náhledy odpovídají finální geometrii. Tisk, dosednutí, stabilita ani provozní teplota nejsou fyzicky ověřené.

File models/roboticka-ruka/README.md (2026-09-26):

# Robotická ruka — první prototyp na autíčko

Zadání Jiřího z 23. 9. 2026: lehký první tisknutelný základ paže pro kolového humanoidního robota na jednoduchém autíčku. Nohy se nyní neřeší. Krokový motor, který má Jiří k dispozici, má otáčet základnou kolem svislé osy; rameno a loket budou v první revizi ručně polohovatelné. Koncovka bude jednoduchá otevřená dvouprstá ruka pro zkoušku tvaru a dosahu, ještě bez aktivního úchopu.

**Stav 23. 9. 2026: první CAD a dvě nastavené tiskové podložky jsou hotové a místně nařezané.** Je to tisknutelný prototyp pro zkoušku sestavení, ne fyzicky vytištěná ani smontovaná paže. Původní [střecha autíčka](../jednoduche-auticko/strecha.md) zůstává samostatným dílem. Nová plošina přebírá její čtyři spodní dosedy a při zkoušce ji nahrazuje. Rozměry konkrétního motoru je potřeba ověřit měrkou, než se vytiskne celá sestava.

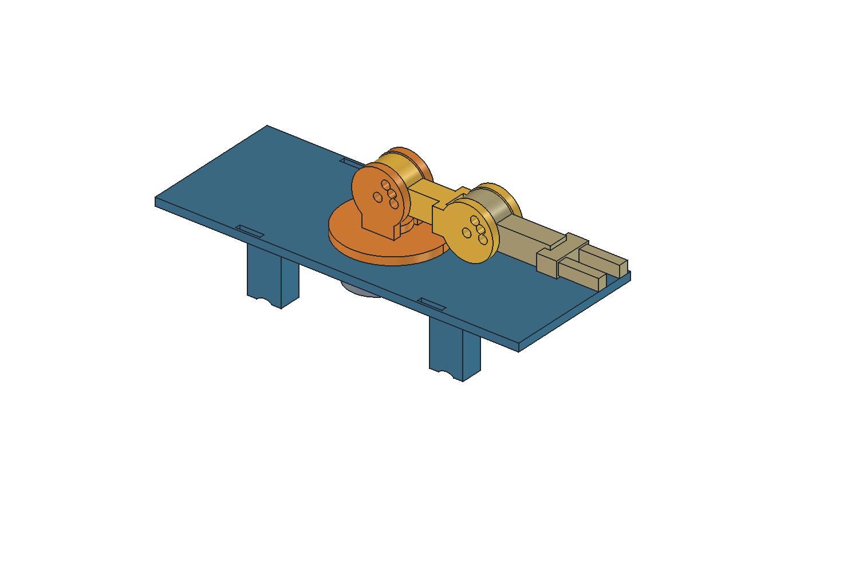
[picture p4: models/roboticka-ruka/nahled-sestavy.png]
CAD náhled první robotické ruky


## Co je připravené

| Soubor | Účel |
|---|---|
| [Měrka motoru – nastavený 3MF projekt](rozlozeni/podlozka-merka-01-nastaveny-projekt.3mf) | První tisk, jeden zkušební kus |
| [Sestava – nastavený 3MF projekt](rozlozeni/podlozka-sestava-01-nastaveny-projekt.3mf) | Druhý tisk, všech 12 fyzických montážních kusů |
| [Přehled tiskových podložek](rozlozeni/README.md) | Přesné počty, náhledy, profil, podpory a výsledky řezu |
| [Editovatelný model FreeCAD](roboticka-ruka.FCStd) a [zdrojové makro](roboticka-ruka.FCMacro) | Parametrický zdroj sedmi typů dílů |
| [STL](stl/) a [náhled spodku plošiny](nahled-spodku.png) | Jednotlivé exporty a kontrola motorového prostoru |

Model tvoří výměnná plošina, otočná základna, nadloktí, předloktí s pevně otevřenou dvouprstou rukou, čtyři čepy a čtyři C-pojistky. Dva čepy na každém kloubu tvoří osu a aretaci; rameno a loket lze ručně nastavit do navržených poloh **0°, 30° a 60° směrem nahoru**. Otočná základna má kluzný prstenec opřený o plošinu, aby část svislé zátěže nemusela nést samotná převodovka motoru. Uložení, vůle a skutečná nosnost ještě nejsou fyzicky prokázané.

## Postup první zkoušky

1. Otevři celý [projekt měrky](rozlozeni/podlozka-merka-01-nastaveny-projekt.3mf) v Anycubic Slicer Next a vytiskni jeden kus. Porovnej rozteč děr a profil otvoru se skutečným motorem. Pokud nesedí, oprav parametrický zdroj a znovu připrav STL i obě podložky.
2. Až poté otevři celý [projekt sestavy](rozlozeni/podlozka-sestava-01-nastaveny-projekt.3mf) jednou, bez přidávání kopií. Jde o projekt pro **Anycubic Kobra X 0,4 mm** s procesem 0,16 mm a nekalibrovaným profilem odvozeným ze systémového Anycubic PLA. Podložka je nastavena na 50 °C pro první i další vrstvy. V tiskárně/sliceru zkontroluj skutečně vloženou PLA cívku; profil není kalibrací Jiřího Alzament PLA Basic. Místní řez měrky je bez varování, u sestavy zůstává pouze [varování režimu časosběru](rozlozeni/README.md#proces-a-podpory). Při změně profilu znovu zkontroluj řez a dráhy.
3. Po tisku odstraň podpory pouze z otočné základny a vyčisti kluznou plochu, otvor hřídele i otvory kloubů. Nasazení čepů, pojistek a hřídele zkoušej bez násilí; vůle jsou návrhové.
4. Při vypnutém autíčku zkontroluj volný prostor pod plošinou a připevni motor zespodu dvěma šrouby a maticemi M3. Návrh otvorů a zahloubení počítá s nízkou hlavou do průměru 7 mm a výšky 2 mm; skutečnou délku šroubů a jejich dostupnost je třeba ověřit na motoru. Po sestavení otočné základny spoj nadloktí a předloktí čepy s C-pojistkami a nastav obě aretace nejprve na 0°.
5. Vyměň původní střechu za novou plošinu a nejprve zkoušej **na stojícím autíčku bez nákladu v ruce**. Čtyři dosedy jsou převzaté z původní střechy, ale samy nevytvářejí zámek proti zvednutí. Před jízdou ověř fyzicky dosednutí a bezpečné zajištění plošiny k podvozku. Trasu kabelu motoru a meze otáčení ověř dřív, než se základna začne motorově otáčet; nepouštěj ji nepřetržitě dokola.

Nová plošina zabírá místo dosavadní volné horní plochy, takže umístění existující elektroniky a kabelů autíčka bude potřeba při montáži přehodnotit. Návod k elektrickému připojení zatím neexistuje; [stav elektroniky](../../elektronika/roboticka-ruka/README.md) jej výslovně odděluje od mechanického tisku.

## Co je potvrzené a co je návrh

Jiří potvrdil vlastnictví motoru se štítkem hlasem čteným jako „StepMotor 28BY…-48, 5 V DC“. Přesné označení a rozměry fyzického kusu nejsou jisté; [zápis ve skladu](../../elektronika/vybaveni.md) tuto nejistotu zachovává. [Běžný typ 28BYJ-48 u LaskaKitu](https://www.laskakit.cz/krokovy-motor-28byj-48/) je vodítkem pro první návrhové hodnoty, nikoli měřením tohoto motoru.

Nominální rozměry použité v modelu jsou tělo Ø28 mm, rozteč montážních otvorů 35 mm a hřídel Ø5 mm s ploškami. Podklady jsou [výkres varianty 28BYJ48-W01](https://akizukidenshi.com/goodsaffix/28BYJ48-W01.pdf) a [popis 28BYJ-48 od Waveshare](https://www.waveshare.com/product/5v-step-motor.htm). Jsou to **návrhové hodnoty**, ne změřené hodnoty Jiřího kusu.

Nosnost ramene, momentová rezerva, vůle otočné základny, stabilita auta, skutečný dosed nové plošiny a vhodnost šroubů zatím nejsou fyzicky ověřené. Při první zkoušce pohybuj paží bez zátěže a sleduj naklánění auta i případné drhnutí.

Elektrické zapojení a plán případného řízení motoru jsou v [samostatném záznamu elektroniky](../../elektronika/roboticka-ruka/README.md). Pro tuto revizi nebyl připraven ani nahrán žádný firmware.

## Digitální kontrola a další úpravy

[Kontrola geometrie](kontrola-geometrie.json) ověřila sedm platných jednodílných solidů a uzavřené STL. [Kontrola sestavy](kontrola-sestavy.json) nenašla průnik nové plošiny s původní CAD sestavou autíčka ani s nominálním obrysem motoru. Kontrola současně potvrdila volný prostor ve směru navržených aretačních poloh 0°, 30° a 60°; polohy dolů narážely do plošiny, a proto nejsou pro tento prototyp určené. Zkouška změny rozteče motorových děr 35 → 36 → 35 mm ověřila, že se odpovídající otvory plošiny a měrky přepočítají společně. [Audit podložek a místního řezu](rozlozeni/README.md#co-bylo-ověřeno-v-počítači) ověřil 1 + 12 kopií, skutečně vytvořené podpory otočné základny a průchod slicerem. Žádná tisková úloha nebyla odeslána.

Hlavní rozměry jsou v tabulce `Parameters` ve FreeCAD souboru a v `VALUES` zdrojového makra. Standardní objekty FreeCAD mají vazby na tabulku. Některé odvozené tvary, zejména poloměr a úhly aretačních děr, vznikají při spuštění makra: při jejich změně uprav makro, přegeneruj model a znovu vytvoř STL i 3MF. U změny provedené nejprve v FCStd slaď také makro, aby příští regenerace změnu neztratila. Makro přepisuje vlastní FCStd, STL a kontrolní JSON v této složce; otevřený cílový FCStd odmítne přepsat. Náhledy a 3MF se vytvářejí navazujícími postupy, ne samotným makrem.

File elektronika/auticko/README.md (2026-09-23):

# Elektronika autíčka

**23. 9. 2026 — Jiří po zkoušce aktuální `v3-reverse-v1` řekl: „Hele, všechno to funguje“.** Jde o obecnou uživatelskou fyzickou akceptaci po předání postupu jízdy vpřed a couvání, nikoli samostatně doložené měření proudu, průběh změny směru nebo dlouhodobou zkoušku. Následně potvrdil „Hotovo“ po postupu úplného vypnutí: pustit ovladače, zastavit kola, vyjmout jeden článek motorového zdroje, odpojit plus servo zdroje od červeného vodiče serva, zaizolovat volný plus a odpojit USB. Jde o uživatelské potvrzení dokončení postupu, nikoli nezávislou kontrolu jednotlivých spojů.

**Nahraná verze — couvání `v3-reverse-v1`:** obsahuje tlačítko **Držet pro couvání** a ArrowDown, motorový povel −1/0/1 a opačnou polaritu při stejném PWM 128/255. Servo zůstává na 1275 / 1575 / 1875 µs při 50 Hz; směry kol se při couvání neobracejí a řídicí vstupy L293D se nepřepojují. **Nová verze je nahraná; uživatel následně obecně potvrdil funkčnost („Hele, všechno to funguje“).** Zdroj SHA256 `d24a87631fd32a41685baedd7488c425a75ca6f9e300706349c61e09e79fe930`; překlad a úplné offline regrese prošly. Upload **86 716 B / 22 stran / exit 0** a tři pasivní výpisy potvrdily novou verzi a klidové výstupy. Čítače zařízení byly stabilní **HTTP=29 / closed=29**; původ dřívějších požadavků není určený. Agent odeslal 0 sériových dat, 0 HTTP a 0 pohybových povelů; port je zavřený a volný. **Po následné zkoušce uživatel obecně potvrdil funkčnost; agent pohyb ani elektrické měření PWM neprováděl.** [Evidence uploadu](../../models/jednoduche-auticko/firmware/prvni-motor/evidence/2026-09-23-v3-reverse-v1-upload/README.md). Níže uvedená akceptace neutrální polohy patří historické v4 a nepřenáší se na nový hash.

Konflikt vpřed/vzad vyvolá STOP. Opačný směr vyžaduje nejméně 250 ms od skutečného vypnutí výstupu; při předčasném požadavku se relace zruší a je nutné **pustit všechny ovladače a znovu stisknout**. Časovač, opakovaný HOLD ani puštění jednoho ovladače motor samy neobnoví. Těchto 250 ms nedokazuje mechanické zastavení; dosavadní 500ms povolení a konzervativní mez až 1 s při ztraceném STOP zůstávají. Upload je dokončený; [první fyzická zkouška](rizeni-v3.md#příští-zkouška-couvání--zatím-neprovedená) má nyní obecné uživatelské potvrzení funkčnosti.

**Historická kalibrace řízení:** Dříve byl nahraný **`v3-steering-v4`: střed 1575 µs, zachované ±300 µs a 50 Hz (1275 / 1575 / 1875 µs)**. Upload **84 948 B / 21 stran / exit 0** a tři pasivní USB výpisy potvrdily novou verzi, klid motoru, `steeringUs=neutralUs=1575` a `rangeUs=300`. **Uživatel následně s připojeným táhlem, koly nad stolem, motorem bez napájení a povelem Rovně potvrdil správnou neutrální polohu kol: „Super, takhle to je perfektní“.** Jde přímo o +50 µs od v3 ve směru Doprava, bez mezikroku 1550 µs. Uživatel na v3 s připojeným táhlem a povelem Rovně stále hlásil kola mírně doleva; první +25µs trim byl podle něj skoro neznatelný. Potvrzení se týká neutrální polohy kol při krátké zkoušce; nejde o měření úhlu, ověření všech dorazů, dlouhodobého provozu ani jízdy. Pro upload v4 uživatel nově odpověděl „Ano“ na dotaz zahrnující odpojení servo plusu, ponechání UNO na USB a motor bez napájení. Táhlo smí zůstat připojené a před novým odpojením je hlásil připojené. [Chronologie a zapojení](kontrolni-zapojeni.md), [řízení V3](rizeni-v3.md), [firmware a evidence](../../models/jednoduche-auticko/firmware/prvni-motor/README.md). Potvrzený pěkný pohyb volného serva v2 doprava i doleva se nepřenáší na výsledek trimu v4.

**Nové potvrzení před uploadem couvání:** na otázku po USB Arduina a odpojeném napájení motoru i červeném vodiči serva uživatel odpověděl „ano, servo odpojeno“ a upload výslovně autorizoval. Před uploadem byl podle tohoto hlášení servo plus odpojený a motor měl odpojený článek; táhlo se neměnilo. Po pozdější zkoušce uživatel potvrdil dokončení předaného postupu vypnutí („Hotovo“); jednotlivé spoje agent nekontroloval. Jde o uživatelské potvrzení, nikoli elektrické měření.

Poslední **úplná fyzická akceptace motorového ovládání** nadále patří `hold-to-run-v2`; uživatel u ní potvrdil funkční držení, puštění a nový stisk. Je zachovaná v [přesném archivu v2](../../models/jednoduche-auticko/firmware/archiv-hold-to-run-v2/README.md). Její fyzická akceptace se nepřenáší na dnešní upload V3. Původní sekundový stolní test a následná v1 jsou historické kroky; návrat k pulzu uživatel odvolal před uploadem.

## Upload a dnešní zapojení — 22. 9. 2026

`v3-steering-v1` byl nahrán při USB napájení UNO a podle uživatele odpojeném pohonu a servu. Následovaly neúspěšné pokusy se servem, doplnění UNO GND → mínusová lišta, kontrola UI bez napájení serva a měření napětí. Fotografie a následné potvrzení uživatele upřesnily, že mínus nového zdroje byl původně v **IOREF**, přestože dřívější slovní hlášení uvádělo GND. Uživatel výslovně potvrdil jeho přesunutí do správného **GND**. Potom naměřil 6,35 V bez USB i s USB a při krátkém pokusu poprvé hlásil klidné servo a malý pohyb na směrové tlačítko. Změna zapojení a hlášený pohyb mají časovou návaznost; není tím prokázaná příčina všech předchozích výpadků ani nepřítomnost poškození.

Podrobná [chronologie včetně původu měření, fotografií a otevřených bodů](kontrolni-zapojeni.md#hlasova-zkouska-22-9-2026) je kanonickým záznamem této fyzické zkoušky. Měření bylo mezi volným plusem zdroje a hnědým kontaktem serva, bez zátěže. Regulovaných 5 V není hotových; uživatel měnič nemá a přijal riziko přímého 6,35V pokusu nad uváděným rozsahem SG90 4,8–6 V. Motorový držák má podle posledního hlášení jen tři zapojené články, čtvrtý je odpojený.

**Historické potvrzení před uploadem v2:** uživatel výslovně potvrdil **červený plus serva odpojený, motor bez napájení, táhlo od kol odpojené a UNO na USB**. Toto nové hlášení nahrazuje dřívější nejistý stav odpojení. Jde o uživatelské potvrzení, nikoli přímé měření agentem. `v3-steering-v2` byl následně nahrán a potvrzen třemi klidovými USB výpisy; piny a ovládací protokol se nemění. Agent neposlal sériová data, HTTP ani pohybové povely a port uzavřel. Následně uživatel výslovně potvrdil pohyb volného serva oběma směry na v2. Původní koordinátor mu potom popsal Rovně, odpojení servo plusu a USB, srovnání kol a připojení táhla bez násilí. Následné hlášení mírného levého natočení kol je podkladem pro požadovaný trim +25 µs ve směru Doprava; není potvrzením provedení všech předchozích pokynů ani plnou akceptací dorazů, zatížení nebo jízdy. [Přesná navazující chronologie](kontrolni-zapojeni.md#hlasova-zkouska-22-9-2026) rozlišuje fyzicky hlášenou zkoušku v2, nedostatečný první trim v3 s připojeným táhlem a druhý trim v4 s nově uživatelsky přijatou neutrální polohou kol.

## Historické sestavování řízení — hlasové hlášení 20. 9. 2026

Uživatel po odpojení USB a přerušení bateriového napájení potvrdil oranžový vodič SG90 → UNO D9 a hnědý → UNO GND. Červený zůstal podle instrukce volný a oddělený; páčka/táhlo, napájení a fyzická zkouška nejsou potvrzené. **K 20. 9. nový upload neproběhl; upload z 22. 9. je popsaný výše.** Napájení serva uživatel naposledy výslovně odložil. Tehdejší [bod pokračování](rizeni-v3.md#kde-hovor-skončil-a-jak-navázat) byl potvrzení připojení UNO datovým USB k počítači při odpojeném bateriovém napájení motoru a nenapájeném servu; tento fyzický krok ještě nepotvrdil. Měření držáku ani identifikace USB-A vodičů už nejsou následujícím úkolem.

## Softwarová příprava řízení k 20. 9. 2026

- V3 zachovává motorové D5/D7/D8, směr a PWM. Přidává SG90 na digitálním D9 s počátečními pulzy 1500 ±150 µs při 50 Hz; nejde o změřené úhly konkrétního serva.
- Po zapnutí servo dostane povel na nominální střed, takže se může pohnout. První nastavení plánovat bez páčky/táhla a s odpojeným napájením motoru. Při této softwarové přípravě k 20. 9. žádné servo nebylo ovládané.
- Samotné zatáčení motor nezapne. Puštění směru zadá střed, puštění jízdy vypne motor i při drženém směru. Ztráta spojení ukončí povolení pro obě akce; fyzický návrat kol na střed zatím nebyl změřený.
- Podmíněný návrh napájení původně používal druhý 5V USB výstup powerbanky přímo pro servo se společnou GND. Později uživatel přečetl štítky včetně 5 V / 3 A, ale upravený USB kabel nemá určenou napájecí dvojici. K 20. 9. bylo řešení zdroje výslovně odložené a napájení serva nepotvrzené; pozdější pokus z 22. 9. je uveden výše. Detail je v [návodu V3](rizeni-v3.md#napájení-z-dostupného-vybavení).
- Softwarová příprava měnila zdroj, testy a dokumentaci, bez CAD, tiskové sady, uploadu či hardwarových úkonů. Následné uživatelské propojení dvou vodičů je zaznamenané samostatně výše.

## Poslední fyzicky přijatá motorová zkouška — 19. 9. 2026

- Požadované chování: souvislé držení udržuje běh, puštění zastaví. Nový stisk po chybě obnoví relaci bez ručního reloadu; nikdy automatické rozjetí.
- V2: 80 504 B flash / 9 792 B RAM; upload 80 512 B, 20 stran, exit 0. USB ověřilo v2 a vypnuté výstupy. Testy i skutečný upload popisuje [firmware](../../models/jednoduche-auticko/firmware/prvni-motor/README.md). Po návratu uživatel obnovil stránku a potvrdil funkční držení, puštění a nový stisk („Jo, funguje to, perfektní“). Fyzická akceptace tohoto základního ovládání je potvrzená uživatelským hlášením; časování a chování při všech síťových poruchách nejsou fyzicky změřené.
- Zapojení a PWM se nemění. Samostatný časovač vypne běh po 500 ms bez platného HOLD; při ztraceném STOP a jednom již odeslaném HOLD je konzervativní hranice až 1 s od puštění. Motor volně dobíhá.
- Neoznačený motor, jeho proud a napětí při rozběhu nejsou změřené. Těžký rozjezd existoval již na starém pulzním programu. [Historie potíží](potize-po-montazi.md) není uzavřená jako fyzicky vyřešená.
- Mechanická V2 s převodovkou 12:1 má nově uživatelem hlášené opakované zasekávání; podezření na rozpěrku, vliv lepidla/oleje i uložení jsou nepotvrzené. [Audit V2](../../models/auticko-s-prevodovkou/revize-prevodovky.md) je samostatný od firmwaru `hold-to-run-v2`; nyní se firmware ani pohon neovládaly.
- Horní plošinu uživatel vytiskl a nasadil; dosed, vůle a nosnost neověřené. Nářadí, nové baterie a silikonový olej jsou v [inventáři](../vybaveni.md), jejich použití se neodvozuje z nákupu.

## Historie verze při držení tlačítka

Následující popis a kontroly patří dříve nahrané verzi `hold-to-run-v1` (`46cee7f5…`), nikoli nové v2. Po uvolnění, zrušeném dotyku, ztrátě focusu, skrytí stránky nebo offline události prohlížeč ukončuje držení a posílá STOP. Při ztraceném STOP či čekání Wi-Fi hlídá vypnutí samostatné přerušení časovače každých 5 ms: přibližně po 0,5 s od poslední platné výzvy serveru. Skutečné fyzické časování nebylo měřené a tato ochrana neřeší zamrznutí procesoru či dlouho zakázaná přerušení. Po vypršení povolení nebo obnovení spojení se pohon sám neobnoví; je nutný nový stisk.

Překlad má **78 808 B flash / 9 068 B RAM**, úspěšný upload **78 816 B / 20 stran**. Prošlo **82 případů parseru + 82 celého loop**, **19 skupin protokolu, zotavení a selhání**, zkoušky přerušení při **7 blokujících operacích** a **19 scénářů skutečného JavaScriptu v Node**. Jde o hostové simulace. Uživatel nový režim nejprve hodnotil příznivě, nyní ale hlásí neúspěšný rozjezd i s koly ve vzduchu. Těžký rozjezd podle jeho upřesnění existoval už na starém programu; příčina ani regrese nové verze nejsou prokázané. [Návod k aktuálnímu firmwaru](../../models/jednoduche-auticko/firmware/prvni-motor/README.md) a [úplný záznam nahrání](diagnostika-webu.md#historický-upload--ovládání-při-držení-v1) rozlišují rozsah ověření.

## Dokumentace

- **[Kontrolní zapojení celého obvodu](kontrolni-zapojeni.md)** — přístupný pinout, seznam spojů, aktuální fyzický stav a hlasový záznam zkoušky; [SVG nákres](kontrolni-zapojeni.svg), [PNG náhled](kontrolni-zapojeni.png).
- **[Řízení V3 se SG90](rizeni-v3.md)** — nové ovládání, podmíněné napájení ze stávajícího vybavení, nastavení středu a meze ověření.
- **[Aktuální potíže po montáži](potize-po-montazi.md)** — nepravidelný rozjezd, neobvyklý zvuk, použití silikonového oleje a omezení sériové diagnostiky.

- [Zapojení L293D](zapojeni-l293d.md) — piny, napájení a omezení dosavadní zkoušky.
- [První stolní zkouška](prvni-stolni-test.md) — hlášený motorový výsledek, fotografie a opravy během sestavování.
- [Diagnostika a oprava webu](diagnostika-webu.md) — historie Wi-Fi 255, recovery a navazující upload ovládání při držení.
- [Elektronika a historie zprovoznění](elektronika.md) — součástky, USB, původní požadavky a software.
- [Firmware a jeho ověření](../../models/jednoduche-auticko/firmware/prvni-motor/README.md) — zdroj zatím zůstává u modelu.
- [Vybavení](../vybaveni.md), [snímatelná plošina](../../models/jednoduche-auticko/strecha.md) a [deník tisků](../../docs/denik-tisku.md).

Při dalším sestavování postupovat po jednom konkrétním kroku. Zachovat určení řídicích pinů D5 → pin 1, D7 → pin 2 a uživatelem potvrzené propojení D8 → pin 7; barva vodiče nenahrazuje určení pinu. Nákup páječky ani baterií není potvrzením jejich použití.

## Nová mechanická konstrukce

[Autíčko s převodovkou 12:1](../../models/auticko-s-prevodovkou/README.md) je dokončený samostatný model s užitnou elektronickou plochou 170 × 60 mm. [Tiskový ZIP](../../models/auticko-s-prevodovkou/tiskovy-balicek.zip) obsahuje 20 kusů, každý přiložený STL tisknout jednou. Kontroly CAD, exportů a montážních vůlí prošly; fyzický tisk a montáž teprve proběhnou. Piny, výkon PWM a stávající elektronika se kvůli němu nemění. Dva vnější záběry mění výsledný směr oproti původnímu jednomu záběru; při montáži ověřit směr a podle potřeby s odpojeným napájením zaměnit dva motorové vodiče. Převodová redukce není důkazem odstranění neznámého elektrického či mechanického problému.

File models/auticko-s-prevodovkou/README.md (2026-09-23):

# Autíčko s převodovkou 12:1

Nový samostatný mechanický prototyp s poháněnou společnou zadní osou, dvěma volnými předními koly a snímatelnou horní plošinou. Původní [autíčko](../jednoduche-auticko/README.md) a jeho střecha zůstávají zachované. Nové osy, kola, pojistky, rám ani plošinu se starými díly nekombinuj. Výjimkou je tentýž motor a geometricky shodný původní pastorek18z s otvorem2,2 mm; jeho opětovné použití závisí na nepoškozeném uložení a nasazení.

**Aktuální stav: uživatel fyzicky zkouší V2 a hlásí opakované zasekávání převodovky.** Použil sekundové lepidlo a potom olej; místa a množství neznáme. Podezřívá nesprávnou stranu rozpěrky, ale výsledek slíbené přestavby ani zkouška převodu bez motoru zatím nejsou potvrzené. [Technický audit a návrh revize](revize-prevodovky.md) rozlišuje výpočty a hypotézy; navazuje samostatný plně tištěný návrh s větší redukcí. Původní CAD/STL se dosud nemění. Není prokázané, že samotný převod odstraní dosavadní těžký rozjezd/bzučení. Tento problém se podle uživatele objevil už před změnou ovládání; namazání hřídelek silikonovým olejem prý moc nepomohlo. Motor, napájení, tření i přenos momentu pastorkem mají stále neověřené vlastnosti. Aktuální zapojení a firmware patří do [elektroniky](../../elektronika/auticko/README.md), inventář do [vybavení](../../elektronika/vybaveni.md).

## Soubory pro tisk a prohlížení

- [Tiskový balíček ZIP](tiskovy-balicek.zip): každý přiložený STL tisknout jednou; opakované díly mají samostatné očíslované kopie.
- [Parametrický FreeCAD model](auticko-s-prevodovkou.FCStd), [zdrojové makro](auticko-s-prevodovkou.FCMacro), [kontrola geometrie](kontrola-modelu.json).
- [Sestava](sestava.png), [odkrytý pohon](prevodovka.png), [zvednutá plošina](rozlozena-plosina.png), [všechny tiskové díly](tiskove-dily.png). Jde o skutečné CAD náhledy; rozložení dílů je ilustrační, nikoli připravená tisková podložka.

## Co se změnilo

Dvě čelní evolventní soukolí **18:54 a 18:72** dávají celkem **12:1**, modul 0,9 mm, úhel 20°. Původní model měl 18:54, tedy 3:1. Při stejných otáčkách motoru je nová zadní osa ideálně čtyřikrát pomalejší s čtyřikrát větším momentem před ztrátami. Protože se průměr kol zvětšil ze 60 na 80 mm, ideální obvodová rychlost vozítka klesne na třetinu a tažná síla vzroste třikrát. Skutečnou rychlost, sílu ani nosnost bez motorových údajů a fyzické zkoušky nezaručujeme; další soukolí přidává tření.

Větší kola dávají 72zubému kolu nominální světlost 6,7 mm. Tištěné osy mají Ø8 mm, souvislou D plochu a tisknou se naležato pro lepší orientaci vrstev vůči ohybu. Pojistkové drážky mají kořen Ø6,8 mm a za drážkou je 1,5 mm materiálu. Kola jsou bez pneumatik; přilnavost materiálu k povrchu nebyla změřena. Vozítko nemá řízení ani diferenciál. **Dva vnější záběry obracejí směr vůči původnímu jednostupňovému převodu:** zadní osa nyní běží stejným směrem jako motor. Při první zkoušce s koly ve vzduchu ověř směr; případnou záměnu dvou vodičů motoru dělej pouze s vypnutým napájením. Tento CAD úkol firmware nemění.

| Rozměr | Návrh |
|---|---:|
| Rám | 180 × 44 × 4 mm |
| Kola | Ø80 × 8 mm |
| Rozvor | 118 mm |
| Kola přes vnější boky | 96 mm |
| Osa zadní / meziosa / motor / přední (X) | 32 / 72,7 / 105,3 / 150 mm |
| Osy nad spodní stranou rámu (Z) | 24 mm |
| Osové vzdálenosti 1. / 2. stupně | 32,6 / 40,7 mm |
| Plošina vně | 180 × 70 × 4 mm |
| Rovná užitná plocha | **170 × 60 mm**, X5..175, Y−30..30 |
| Spodek / vršek plošiny | Z70 / 74 mm |
| Kola → spodek plošiny | 6 mm |

Motorové tělo **Ø22,5 × 26 mm** a přední hřídel délky **6 mm** pocházejí z ručního měření uživatele s neznámou přesností. Otvor pastorku **2,2 mm**, délka **5,5 mm**, vycházejí z uživatelem potvrzeného nasazení původního pastorku. Není to změřený průměr hřídele ani ověřený přenos momentu. Kulatý otvor je pracovní předpoklad. Motorová reference neobsahuje nezměřené kontakty; zadní čelo Y3 a prostor za ním jsou otevřené. Žádná konkrétní kolébka pro baterie, powerbanku či Arduino není vymyšlená: vybavení se připevňuje na obecnou rovnou plochu.

## Kolik čeho tisknout

| STL | Počet | Orientace |
|---|---:|---|
| [rám](stl/ram.stl) | 1 | základnou dolů |
| [plošina](stl/plosina-170x60.stl) | 1 | rovnou horní plochou dolů, sloupky nahoru |
| [zadní kolo 72z](stl/kolo-zadni-72z.stl) | 1 | vnější plochou kola dolů, ozubením nahoru |
| [zadní pravé kolo](stl/kolo-zadni-prave.stl) | 1 | plochou dolů |
| [přední kolo](stl/kolo-predni.stl) | 2 | plochou dolů |
| [pastorek 18z, otvor 2,2](stl/pastorek-18z-otvor-2_2.stl) | 1 | čelem dolů |
| [mezikolo 54/18z](stl/mezikolo-54_18z.stl) | 1 | velkým kolem dolů |
| [hlavní osa 101,3](stl/osa-hlavni-101_3.stl) | 2 | naležato souvislou D plochou dolů |
| [meziosa 65,2](stl/osa-mezi-65_2.stl) | 1 | naležato souvislou D plochou dolů |
| [rozpěrka 8,6](stl/rozperka-8_6.stl) | 1 | plochou dolů |
| [rozpěrka 17,6](stl/rozperka-17_6.stl) | 3 | plochou dolů |
| [rozpěrka 1,6](stl/rozperka-1_6.stl) | 2 | plochou dolů |
| [C pojistka](stl/pojistka-c.stl) | 3 | plochou dolů |

Celkem **20 tištěných dílů, 13 různých STL**. ZIP už obsahuje počty; po importu jeho souborů znovu nenásobit počty z tabulky. Tisk měřítkem 100 %, jednotky mm. Plošina a rám jsou samostatné díly; netiskne se prostorově sestavený FCStd jako jeden kus.

Všechny STL už jsou v uvedené orientaci na Z0. Pro PLA a 0,4mm trysku je rozumný neověřený začátek 0,16–0,20 mm vrstva; ozubení a osy potřebují dostatek obvodů, např. 4–5. Skutečný profil tiskárny, průtok, smrštění a teploty nejsou tímto modelem ověřené. Při náhledu vrstev zkontrolovat zejména vodorovné otvory uložení Ø8,6, tenké pojistky, spodní hranu zubů a mezery v drážkách. Otvory ložisek obsahují krátké přemostění; plošina se tiskne obrácená a kapsy otevřené nahoru. Zuby nejsou zavěšené nad prázdnem: zadní věnec podpírá široký ráfek a malé mezikolo podpírá disk. Neslibujeme tisk bez potřebné korekce profilu. Pojistky/uložení a otvor pastorku je vhodné ověřit před dlouhým tiskem rámu/plošiny.

## Montáž

Souřadnice: X směrem od zadní k přední nápravě, Y napříč, Z nahoru. Ozubení je na levé straně Y záporné. Pracovat s odpojeným motorovým napájením.

1. Odstranit otřepy a ověřit, že každá osa projde oběma uloženími rámu bez nucení a že se kola/převod mohou volně otáčet. Nenatlačovat nepřesnou D díru násilím; skutečná tisková vůle je neověřená. Přední kola mají kruhový otvor, zadní D otvor.
2. **Zadní osa:** na osu od volného konce navléknout ozubené kolo tak, aby rovná vnější strana ležela u příruby a ozubení mířilo dovnitř. Přidat rozpěrku 8,6. Prostrčit zleva oběma zadními bloky rámu; na pravé straně doplnit rozpěrku 17,6, pravé D kolo a C pojistku do drážky.
3. **Přední osa:** přední volné kolo, rozpěrka 17,6, oba přední bloky, rozpěrka 17,6, druhé volné kolo a pojistka. Přední kola se otáčejí samostatně na D ose; plochá část osy je kvůli tisku, ne k záběru těchto kol.
4. **Meziosa:** od příruby malé 18zubé kolo, směrem k rámu velké 54zubé kolo. Obě jsou jedním tištěným dílem. Navléknout mezikolo a rozpěrku 1,6, prostrčit oběma prostředními bloky, napravo doplnit druhou rozpěrku 1,6 a pojistku. Souvislé D plochy umožňují nasunutí přes celou volnou délku osy.
5. Při zasouvání otáčet koly, aby zuby zapadly do mezer. Zadní pravé kolo a D osa mají stejnou orientaci D plochy jako zadní levé. Pojistka musí skutečně zapadnout do drážky a nesmí axiálně sevřít rotující díly. Zkontrolovat volné otáčení celé převodovky ještě **bez motoru**.
6. Opatrně nasadit pastorek na motorovou hřídel; v CAD je 0,5 mm mezera mezi pastorkem a čelem motoru. Nepřenášet sílu přes ložiska motoru a nepovažovat dosavadní nasazení za zaručené pevné uložení. Motor vložit do dvou sedel, natočený kontakty k otevřenému pravému konci, a připevnit **dvěma vhodnými stahovacími páskami** skrz svislé otvory 3 × 3,2 mm. Pásky jsou potřebný netištěný materiál, jejich konkrétní vlastnictví/rozměr zde netvrdíme.
7. Plošinu nasadit čtyřmi kapsami na horní části předních a zadních bloků. Kapsy mají návrhově 0,3 mm vůli na každé straně a hloubku 2 mm. Samotné kapsy nezajišťují proti nadzvednutí. Pro jízdu ji stáhnout **dvěma vhodně dlouhými páskami** přes boční otvory u X125 a X165 a kolem rámu, mimo kola a soukolí. Potřebný průřez musí projít 3mm šířkou otvoru; délku zvolit podle skutečné trasy a nákladu. Na této trase nesmí být sevřené kabely ani kontakty. Pro sejmutí se pásky uvolní/odstraní; není to pevně zajištěný beznástrojový zámek.
8. Vybavení upevnit samostatně na plošinu, kabely vést mimo zuby a kola, ponechat přístup ke kontaktům motoru. Nejprve ověřit lehkost pohybu a jištění bez napájení, potom řízenou zkoušku s koly ve vzduchu a až následně s lehkým nákladem na zemi. Tato posloupnost je doporučení, nikoli provedený test.

### Montážní stohy a vůle

Hlavní osy začínají Y−50, příruba končí−48, levé kolo leží−48..−40 a pravé40..48. Pravá drážka je48,3..49,8, pojistka48,4..49,7, konec osy51,3. Vzdálenost příruba–vnitřní čelo pojistky je96,4 mm; součet tlouštěk kol, rozpěrek a šířky rámu mezi vnějšími dosedy je95,2 mm. **Celková axiální rezerva hlavního stohu je1,2 mm** (0,4 mezi vnějšími čely kol a dorazy plus0,8 ve vnitřních mezerách). Samotná pojistka má v drážce dalších0,2 mm vůli. Rozpěrky nejsou předepnuté a tření čel může být po tisku jiné.

Meziosa začíná−38,4, příruba končí−36,4. Mezikolo zabírá−36..−24, rozpěrka−23,8..−22,2, rám má vnější dosedy−22 a22, pravá rozpěrka22,2..23,8, pojistka23,9..25,2. Drážka je23,8..25,3 a konec26,8. Mezi dorazy je60,3 mm proti součtu dílů59,2 mm: **celková axiální rezerva meziosového stohu je1,1 mm**, plus0,2 mm vůle pojistky v drážce. Mezi mezikolem a motorovým čelem je nominálně **1 mm**, po využití návrhových axiálních mezer se může zmenšit; tisk ani pružnost se v CAD nesimulují. Malé18z mezikolo navazuje přímo na velké, bez mezery: velké zabíráY−29..−24 a malé−36..−29. Podpěrný disk končíY−29, tedy2 mm od zadního ozubení, aby zůstala rezerva i při součtu axiálních posunů. Mezikolo se nesmí dotýkat motoru. Příruba meziosy míjí levé kolo o nominálně1,6 mm vY.

Uložení Ø8,6 proti oseØ8 dává radiálně0,3 mm. D díry Ø8,3 mají radiálně0,15 mm a plocha3,0 proti2,8 mm dává0,2 mm vůli. To jsou návrhové hodnoty, ne potvrzené vůle po vytištění. Pružnost C pojistek, pevnost os, tření a nosnost plošiny se musí teprve ověřit.

## Parametry a regenerace

Ve FCStd jsou běžné rozměry v tabulce `Parameters`, sloupecB. Model tvoří standardní `Part::Box`, `Part::Cylinder`, booleany, `Part::Extrusion` a `App::Link`; nepotřebuje vlastní Python proxy třídu. Změna průměru kol posune plošinu podle její výškové vazby. Změna osové vůle přepočte polohu meziosy a motoru. Geometrická editovatelnost sama nepotvrzuje sestavitelnost libovolné kombinace.

**Počet zubů, modul a úhel ozubení se mění v konstantách zdrojového makra a vyžadují regeneraci**, obrysy nejsou živý parametrický generátor. Ověřená varianta je pouze12:1. Změna převodu může vyžadovat další změnu otvorů rámu, průměrů prstenců, podepření zubů a vůlí; makro při kolizích končí chybou. Není dovoleno změnit pouze číslo v tabulce a označit obrys za nové ozubení. Také delší osy, tloušťky kol, jejich Y polohy a rozpěrky tvoří jeden montážní stoh: upravit jej společně a znovu zkontrolovat.

Makro zapisuje výhradně vedle sebe a přepisuje místní model, STL, kontrolníJSON a ZIP; náhledy generuje následné [GUI makro](nahled.FCMacro). Neuložené ruční změny před regenerací zálohovat. Spustit přes skutečný FreeCAD1.1.3 popsaný v [software](../../docs/software.md), nikoli běžný Python. Konkrétní izolovaný běh:

```bash
/home/novakj/.cache/freecad-shelf-1.1.3/runtime/AppRun freecadcmd -u /home/novakj/3d-print/models/auticko-s-prevodovkou/.runtime/user.cfg -s /home/novakj/3d-print/models/auticko-s-prevodovkou/.runtime/system.cfg /home/novakj/3d-print/models/auticko-s-prevodovkou/auticko-s-prevodovkou.FCMacro
```

Následné GUI makro použije tutéž cestu s `nahled.FCMacro` bez `freecadcmd`, ideálně v odděleném `xvfb-run` s `LIBGL_ALWAYS_SOFTWARE=1`. Výsledný model se ukládá s viditelnou sestavou; zdroje tiskových dílů a konstrukční tvary jsou skryté.

## Ověření a otevřené body

**Dokončené kontroly 2026-09-19:** všech13 finálních dílů je platný jediný solid a všech13 STL je uzavřená orientovaná manifold síť s jednou souvislou komponentou. ZIP obsahuje20 správných kopií.210 statických dvojic i25 pohybových poloh obou převodů mají nulový objemový průnik; prošly také popsané axiální meze a změna/vrácení tří parametrů. Uložený FCStd se znovu otevřel se správnou viditelností21 objektů sestavy včetně netisknutelné reference motoru. Všechny čtyři skutečné CAD náhledy byly otevřeny a vizuálně zkontrolovány. Původní kontrolované CAD soubory zůstaly shodné hashem.

Přesné výsledky běhu jsou v [kontrola-modelu.json](kontrola-modelu.json). Kontrolujeme každý konečný díl jako jeden platný solid, uzavřenost exportů, všechna statická tělesa sestavy,25 vzorků společného otočení obou soukolí přes jednu rozteč velkého kola a válcové obálky rotujících kol/ozubení proti rámu, plošině a tělu motoru. Doplněná kontrola krajních axiálních posunů používá zadní kolo−1,0/+0,5mm a mezikolo−0,9/+0,5mm; rozšířený test se opakuje po otevření uloženého FCStd. Parametrická zkouška mění a vrací průměr kola80→82, motoru22,5→23 a osovou přirážku0,2→0,3 mm. Následně se model ukládá, otevírá a ověřuje jeho viditelnost. Původní CAD/STL/PNG/makra jsou porovnána hashem.

Nezávislá kontrola skutečných binárních STL a hashů je v [overeni-exportu.json](overeni-exportu.json), reprodukovatelná přes [ověřovací skript](overit-exporty.py). Vedle nulových kolizí má každý pár hlavových kružnic překrytí1,6 mm a ideální příčný součinitel záběru přibližně1,434 / 1,455 při zvětšené osové vzdálenosti. To analyticky potvrzuje překrývající se záběr ideálních evolvent, nikoli funkci vytištěných zubů.

Důkaz nulového objemového průniku nenahrazuje správné vůle skutečného výtisku. Zvětšení každé osové vzdálenosti o0,2 mm poskytuje návrhovou zubovou vůli, nikoli kalibrovaný backlash. Žádné měření únosnosti, účinnosti, tření, deformace, životnosti, proudu či zahřívání motoru, přilnavosti kol ani maximálního zatížení nebylo provedeno. Plošina není univerzální potvrzení kompatibility elektroniky. Při původní přípravě G-code nebyl vytvořen a agent tiskárnu neovládal. Tehdejší fyzicky netestovaný stav již překonalo nové uživatelské hlášení zasekávání; příčina a funkční zlepšení zatím potvrzené nejsou. Historické kontrolní JSON a text v ZIPu zachovávají stav při exportu, aktuální stav je v úvodu a v [revizi](revize-prevodovky.md).

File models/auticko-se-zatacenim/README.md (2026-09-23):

# Autíčko s převodem 12:1 a předním řízením SG90

**Dokončený a geometricky ověřený CAD prototyp; skutečný výtisk, montáž a řízení zatím neověřené.** Aktuální kola mají Ø76 × 12 mm a skutečný tištěný dezén. Původní dvě varianty zůstávají beze změny. Firmware se při této mechanické úpravě nemění.

Nová přední kola se otáčejí samostatně na osičkách těhlic. Svislé čepy jsou podepřené rámem i horní odnímatelnou čelistí. Servo přenáší pouze sílu táhla, nikoli hmotnost kol. Jednoduchý rovnoběžník natáčí obě kola stejným úhlem; není to Ackermannovo řízení, takže v zatáčce očekáváme smýkání pneumatik. Skutečnou sílu potřebnou k zatáčení a schopnost SG90 zatáčet pod zatížením neznáme.

[Celé autíčko:33 tištěných kusů](tiskovy-balicek.zip) · [Jen přestavba z V2:22 kusů](prestavba-z-v2.zip) · [Náhled mechanismu](mechanismus.png)

**Pro tisk celé sestavy na Kobra X použij [připravené rozložení 3MF](rozlozeni/README.md): první podložka 31 kusů, druhá rám a plošina.** Soubory zachovávají samostatné díly, měřítko a navržené tiskové orientace; neobsahují tiskové ani materiálové profily. Není potřeba znovu načítat a rozmísťovat 33 STL.

[Parametrický model](auticko-se-zatacenim.FCStd) · [Generátor](auticko-se-zatacenim.FCMacro) · [Geometrická kontrola](kontrola-modelu.json) · [Původní varianta 12:1](../auticko-s-prevodovkou/README.md) · [Elektronika](../../elektronika/auticko/README.md) · [Inventář](../../elektronika/vybaveni.md)

## Skutečně známé údaje a návrh

- Jiří identifikoval Tower Pro Micro Servo 9g SG-90. Má originální jednoramennou páčku s vnitřním ozubením a středový šroubek. Vzdálenost středu osy ke středu posledního malého otvoru **výslovně změřil 15 mm**. Starší nejednoznačné údaje 20/19 mm tento rozměr nenahrazují.
- Nominální výkres výrobce: tělo 22,7 × 12,2 mm, výška těla 27 mm, celková výška včetně výstupu 30,3 mm, délka přes uši 32,3 mm, spodek → spodní rovina uší 17 mm. Přesný posun osy po délce těla a výška skutečné páčky nejsou kótované. Analogová/digitální varianta se nerozlišila; nepředpokládáme rozsah 180°.
- Rozměry těla, malý otvor páčky a výška páčky **nejsou fyzicky ověřené**. `CaseAxisOffset=5 mm` a tloušťka páčky 2,5 mm jsou označené návrhové hodnoty, nikoli měření. Páskové lože umožňuje posunout servo; před finálním utažením vyrovnat skutečnou osu a klouby do modelových poloh.
- Původní DC motor: uživatelsky změřený válec Ø22,5 × 26 mm, hřídel délky 6 mm. Nominální tištěný otvor pastorku 2,2 mm uživatel nasadil; skutečný průměr hřídele, moment a zatížitelnost nejsou změřené.
- Střed řízení X154, Y±44, Z24; kola Ø76 × 12, středy při rovné jízdě X150,3, Y±59. Zadní náprava X32. Přední rozchod 118 mm je širší než zadní92 mm. Rozšíření kol vede pouze ven, vnitřní čela zůstala na původních pozicích. Konstrukční mechanické dorazy ±24°, zamýšlený provozní rozsah maximálně ±20° před fyzickou kalibrací.
- Servoosa X184/Y0, páčka v nule dozadu; čep páčky X169/Y0. Ramena těhlic délky20, jejich konce X174/Y±44. Příčné táhlo mezi osami88, servotáhlo mezi osami√(44²+5²)=44,283 mm. Celá vazba se přepočítává z tabulky `Steering`.
- Horní plošina má nezměněnou souvislou užitnou plochu **170 × 60 mm**. Je to stejný díl jako u V2, s dosedy X32/150 a Y±18. Zadní kontakty motoru zůstávají přístupné po sejmutí plošiny.

Primární zdroje: [TowerPro SG90 analog](https://towerpro.com.tw/product/sg90-analog/), [TowerPro SG90 digital](https://towerpro.com.tw/product/sg90-7/). Nominální údaje nepotvrzují skutečný rozměr uživatelova kusu ani zatížitelnost celého mechanismu.

## Opětovné použití z V2

Přebíraných **8 typů STL** jsou přesné bajtové kopie z `auticko-s-prevodovkou/stl`, jejich SHA jsou v kontrolním JSON. Beze změny lze použít plošinu, pastorek, mezikolo, meziosu, zadní levou rozpěrku8,6, jednu dlouhou rozpěrku17,6 a dvě krátké1,6. Z šesti velkých C pojistek se tři dají převzít z kompletního V2 a tři je třeba dotisknout. Celkem se převezme **11 fyzických kusů**.

Nový rám nahrazuje rám V2. Nepoužijí se čtyři původní kola, obě dlouhé osy a dvě přední dlouhé rozpěrky: spolu s rámem je to **9 nepotřebných kusů V2**. Nové jsou čtyři širší kola s dezénem, zadní osa109,3 a celý přední mechanismus. Úplná třetí varianta má **33 kusů / 23 typů STL**; přestavba z kompletní V2 vyžaduje **22 nově tištěných kusů**, včetně tří dodatečných velkých C pojistek. Kontrola počtů:20 původních +22 nových −9 nepoužitých =33.

| STL typ | Celkem V3 | Dotisk pro přestavbu V2 |
|---|---:|---:|
| ram-rizeni |1|1|
| plosina-170x60 |1|0|
| kolo-zadni-76x12-72z |1|1|
| kolo-zadni-76x12-prave |1|1|
| kolo-predni-76x12 |2|2|
| pastorek-18z-otvor-2_2 |1|0|
| mezikolo-54_18z |1|0|
| osa-zadni-109_3 |1|1|
| osa-mezi-65_2 |1|0|
| rozperka-8_6 |1|0|
| rozperka-17_6 |1|0|
| rozperka-1_6 |2|0|
| pojistka-c |6|3|
| celist-horni |2|2|
| svisly-cep |2|2|
| tehlice-leva / tehlice-prava |1+1|1+1|
| spojovaci-tahlo |1|1|
| servo-tahlo-r15 |1|1|
| distanc-packy |1|1|
| cep-tahla-dlouhy / cep-tahla-kratky |1+1|1+1|
| pojistka-mala |2|2|

Pracovní předchozí návrh s úzkými Ø80×8 koly zůstal v [historii](historie/pracovni-80x8/README.md); není to další tiskový balíček.

## Kola a tisk

Ozubené levé zadní kolo má celkovou osovou výšku **21 mm = běhoun12 + ozubení9**, ostatní kola12 mm; vyšší údaj ve sliceru je správný. Dezén je součást geometrie FCStd i STL:24 příčných drážek v každé polovině šířky, druhá polovina posunutá o7,5°. Drážky jsou1 mm hluboké a1,6 mm široké; vnější průměr76, kořen74. Souvislá stěna předního a pravého zadního ráfku má pod kořenem3 mm. Na ideálně rovné podložce zůstává geometrický valivý průměr76 mm: drážka zabírá asi2,413°, druhá půlka je posunutá o7,5° a vždy ponechá plný poloměr38 mm. Ø74 označuje kořen drážky, nikoli valivý průměr celého kola. Nominální světlost72z věnce je4,7 mm vůči vnějšímu obvodu; konzervativně3,7 mm při dosednutí až na kořen drážky. Plošina zůstává Z70, nominální mezera nad kolem je8 mm.

Proti Ø80 poskytne Ø76 při stejném momentu ideálně o5,3 % větší obvodovou sílu a o5 % menší rychlost. Převod zůstává12:1. Větší šířka ani dezén **nezaručují lepší tření PLA na konkrétní podlaze**; nejde o gumovou pneumatiku. Větší šířka a posun styčné plochy dále od kingpinu také zvyšují požadavek na servo. Skutečný rozjezd, prokluz, vibrace a moment řízení se ověří fyzicky.

STL jsou v mm, v navržené tiskové orientaci, nejnižší Z=0. U dezénu vzniká v polovině šířky místní1mm radiální převis /1,6mm přemostění; bez skutečného náhledu vrstev a výtisku není prokázán tisk bez podpor. Kola, táhla a pojistky leží plochou na podložce, osy a čepy D plochou dolů, horní čelisti velkou horní plochou dolů (klíč vzhůru), plošina užitnou stranou dolů. Těhlice leží společnou rovinnou plochou zadní strany těla/osičky; jejich vyvýšené rameno a kapsa klipu mohou potřebovat **lokální podpory**. Rám má místní přemostění dolních závěsů a klipových otvorů; zkontrolovat náhled podpor, neuzavřít dráhu dorazů. Žádný konkrétní slicerový profil ani G-code nebyl vytvořen nebo odeslán. Materiál, pružnost pojistek a orientace vrstev vyžadují zkušební tisk; netvrdit ověřené nastavení trysky/teploty.

## Spoje a montážní omezení

Tištěná osička kola má Ø8, kruhový otvor kola Ø8,6; svislé čepy Ø8 proti otvorům8,6; klouby táhel Ø6 proti otvorům6,5. Vůle jsou návrhové. Jemný tisk, odstranění otřepů a skutečná volnost chodu se musí ověřit. Netvrdit ověřený press-fit ani nosnost tištěných os/pojistek.

Originální páčku upevňuje její dodaný středový šroubek. Pro poslední malý otvor je navržen **1× šroub M2×16, 2× podložka M2 a 1× pojistná matice M2**; vlastnictví tohoto materiálu není potvrzené. Tištěné servotáhlo má otvor2,3. Před montáží ověřit otvor v originální páčce, tloušťku páčky a průchodnost šroubu; nevnucovat šroub do menší díry. Případnou úpravu otvoru provést až po ověření zbývající stěny a uchycení. Spoj musí zůstat otočný, nesmí být sevřený. Délka šroubu a výška distančního válečku se ověří podle skutečné páčky; nevhodný spoj nenahrazovat násilným utažením.

Servo se uchytí dvěma malými stahovacími páskami přes otevřené lože; potřebný materiál navíc k dvěma páskům motoru. Otvory jsou pro návrhovou šířku pásku maximálně2,5 mm, vlastnictví/typ nepotvrzen. Udržet kabel mimo táhla, ozubení a kola. Vyjímatelná plošina potřebuje podle uživatelem zvoleného zatížení vlastní zajištění; těsný fit a nosnost nepovažovat za potvrzené.

Před spojováním odpojit motorové napájení. Nejdříve sestavit a ručně projít celý podvozek bez servotáhla. **Levá těhlice (L) patří na stranu zadního ozubeného kola, tedy Y− v modelu; pravá na opačnou stranu.** Asymetrické těhlice neprohazovat. Vložit těhlice mezi čelisti, nasadit horní čelisti klíčem do registru, svislé čepy shora a C pojistky radiálně z vnější strany příčníku. Ústí pojistky při nasouvání směřuje k ose; netlačit ji axiálně přes plný konec čepu. Potom nasadit přední kola a jejich C pojistky. Připojit příčné táhlo, malé čepy a pojistky. Malé pojistky nasouvat do přední kapsy zepředu, s ústím směrem dozadu k ose čepu; kulatá drážka dovoluje následné pootočení do jiné orientace zobrazené v CAD. Nakonec nastavit servo do neutrálu a připojit originální páčku a servotáhlo bez předpětí. Dorazy chrání geometrii, **nejsou příkazem pro servo, aby do nich tlačilo**.

Řízení potřebuje samostatné budoucí ovládání/napájení serva. V této etapě se na Arduino nic nenahrálo, servo nepřipojovalo a nezkoušelo. Moment SG90, tření kol a napájecí stabilita se z CAD neprokazují. Dříve hlášený těžký rozjezd existoval i se starým pulzním firmwarem; silikonový olej podle uživatele moc nepomohl. Převod ani servo nejsou prokázanou opravou jeho příčiny.

## Parametry a regenerace

Tabulka `Parameters` zachovává původní standardní graf pohonu, `Steering` řídí nové vazby. Živě svázané jsou zejména `WheelAngle`, `HornRadius`, `ServoX`, `KingpinX`, `HalfTrack`, `StopAngle` a rozměry drážek dezénu. Změna radiusu automaticky přepočte neutrální délku servotáhla; u hotového fyzického táhla se samozřejmě délka sama nezmění. `DeckBottom=70 mm` je záměrně pevné kvůli přesné kompatibilitě plošiny V2.

`Arm` mění kinematické osy a oko, ale nosné bloky ramene mají v makru pevné rozměry; neprovádět samostatnou změnu této hodnoty bez úpravy podpory oka a nového ověření. Řádky označené „konstrukční informace“ nejsou samostatné všestranné nastavovače: `PinDiameter`, `PinClearance`, `BodyRadius`, `WheelOffset`, `KnuckleBottom`, `KnuckleTop`, `JointDiameter`, `JointBore` a `WorkingAngle` vyžadují související změny makra a novou kontrolu. Počet drážek24 je konstanta generátoru. Po jakékoli změně rozměrů znovu exportovat a zkontrolovat sestavu; nestačí upravit buňku a ponechat staré STL.

Generátor čte předchozí FCStd a ihned pracuje s jeho kopií v této složce; předchozí dokument neukládá. Přepisuje pouze místní model, STL a kontrolní JSON. Spustit v izolovaném FreeCADu postupem z [dokumentace softwaru](../../docs/software.md), pak spustit `kinematika.py`, `overit-rizeni.FCMacro`, `overit-vule.FCMacro`, `nahled.FCMacro` a `overit-exporty.py`. GUI náhled zároveň uloží správnou viditelnost finální sestavy a ověří ji znovuotevřením. Neměnit osobní FreeCAD konfiguraci ani spouštět historické makro bez úpravy výstupních cest.

## Co geometrická kontrola neprokazuje

CAD a matematická vazba nedokazují pevnost, životnost, skutečný fit SG90, průchod M2 otvorem páčky, správný šroub, vůle po vytištění, sílu serva, napájení, přenos momentu přes spline/pastorek ani bezpečné jízdní vlastnosti. Doraz je tištěná mechanická součást a může se deformovat nebo zlomit. První zkouška má ručně ověřit volný celý rozsah bez motorového napájení; skutečné ovládání serva a jeho elektrické napájení jsou další samostatná etapa. Model nemá diferenciál ani ložiska, takže zatáčení může vyžadovat větší sílu a kola mohou smýkat.

## Provedené kontroly

Výsledky jsou uložené v [kontrola-modelu.json](kontrola-modelu.json), [kinematika.json](kinematika.json) a [hash/mesh manifestu](overeni-exportu.json). Kontroly se týkají přesné dodané varianty, nikoli libovolných budoucích změn parametrů.

- Nové díly: validní jediný solid; exportované STL: jedna souvislá uzavřená orientovaná mesh, kladný objem, Z0. Převzatých8 typů má shodné SHA s V2; předchozí modely zůstaly beze změny.
- Skutečné objemy sestavy a celé rotační obálky předních kol:25 poloh po2° od−24° do+24°, bez průniku. To je vzorkovaná CAD kontrola, nikoli nekonečně jemný důkaz všech deformovaných fyzických poloh.
- Geometrické dorazy: v±24,5° vzniká očekávaný průnik čepu s dorazem, tedy další volný pohyb modelu už není možný. Pracovní cíl je±20°, aby servo záměrně netlačilo do dorazu.
- Uzavřená servo vazba:4801 poloh po0,01°, bez mrtvého bodu a změny směru převodu; maximální délková odchylka1,5×10⁻¹⁴ mm. Nejmenší účinné rameno u kola18,07 mm a u serva12,29 mm. Uživatelův radius15 je použit ve všech kontrolách.
- Změny a vrácení `HornRadius15→14,5→15`, `StopAngle24→23→24`, `HalfTrack44→45→44` změnily skutečnou geometrii a po návratu obnovily objemy přesně.
- Samostatná zkouška axiálních mezí předních kol:−0,2 mm dovnitř /+0,5 mm ven včetně0,1 mm dodatečného pohybu pojistky, při−24/0/+24°;156 objemových porovnání bez průniku. Zadní převod:4 kombinace původních axiálních mezí bez průniku. Nominální rejd a tento axiální test jsou oddělená kontrola.
- Geometrie zadního72z věnce v montážní rovině je přesně stejná jako V2: objem symetrického rozdílu0 mm³. Nezměněné soukolí nepodstoupilo zbytečně opakovaný celý test; jeho původní záběr dokládá [kontrola V2](../auticko-s-prevodovkou/kontrola-modelu.json).
- Bodové kontroly v tělese potvrzují střídavé drážky dezénu, nejde o obrázkovou texturu. Skutečné GUI náhledy ukazují rovně, oba směry a mechanismus bez plošiny; uložený FCStd se otevírá v přímé poloze s viditelnou finální sestavou.

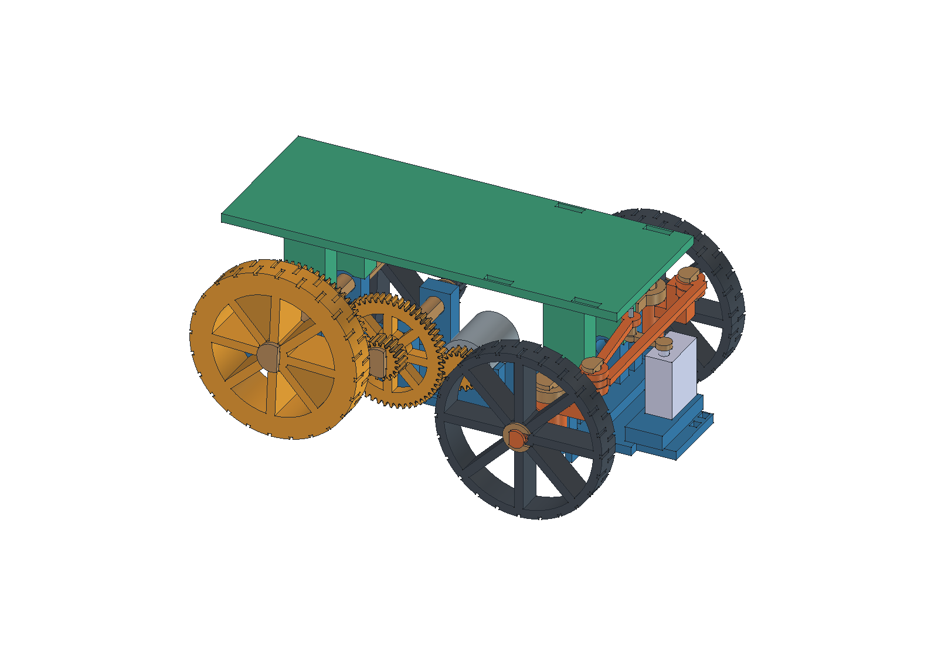
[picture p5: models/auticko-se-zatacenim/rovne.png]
Přímá poloha

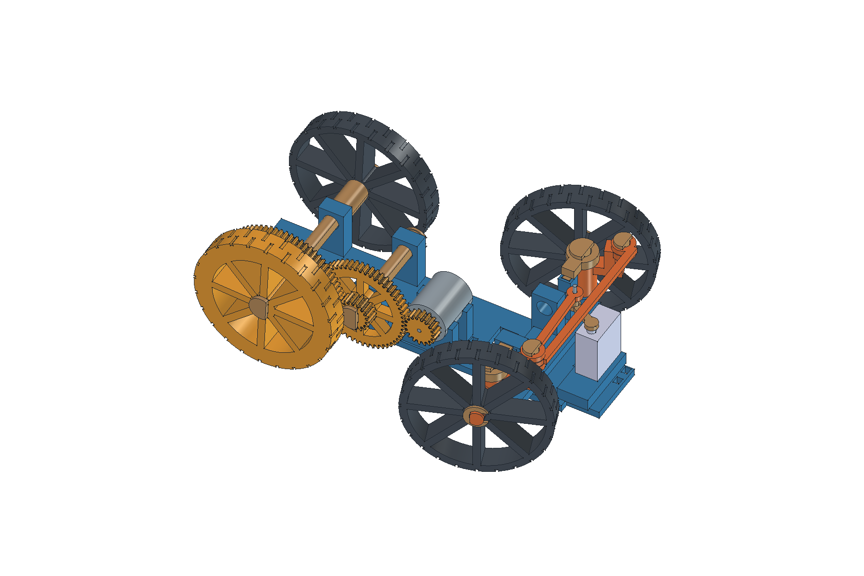
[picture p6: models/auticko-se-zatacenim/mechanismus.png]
Mechanismus bez plošiny


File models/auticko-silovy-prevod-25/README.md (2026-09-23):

# Revidovaná V3: převod 25:1 a přední řízení SG90

**Tiskový prototyp po revizi fitů z 20. 9. 2026: celé autíčko, 34 typů a 66 fyzických dílů na třech podložkách.** Zachovává původní ozubení 20° / modul 1 a nominální rozteče. Otvory jsou upravené podle kalibrace a funkce spoje. Na výslovné zadání se předává celá sada bez dalších povinných zkušebních výtisků.

**Fyzický stav 20. 9. 2026:** obě první várky jsou dokončené a částečně vadné. Pro další tisk je hotová [kombinovaná03 — jedna podložka,26 kusů](rozlozeni/kombinovana-03-2026-09-20/README.md):13 dosud netištěných +7 náhrad první várky +6 druhé. Všech26 je skutečně naslicováno, čepy a osa nastojato, obě těhlice i plošina s připravenými podporami. Nahrazuje samostatnou původní03 a všechny tři podložky sedmidílného dotisku; jejich kopie nepřidávat. **Rám, víko objímky páčky a úplnost obou motorových klínků zůstávají otevřené.** CAD/STL/ZIP a rozměry sestavy jsou zachované; počítačová kontrola není fyzická montáž.

Nominální CAD a exporty jsou ověřené; fyzický výsledek se posuzuje samostatně. **Scénář, ve kterém se celá nominální CAD vůle projeví jako skutečná radiální vůle, neprošel a zůstává označený `false`.** Není podmínkou tohoto autorizovaného prototypu. Chod, fit, nosnost a životnost celého nového výtisku zatím nejsou potvrzené. [Přesný rozsah kontroly](#co-je-ověřené) a [historie revize](revize-fitu-2026-09-20.md).

## Soubory k tisku a prohlížení

**Aktuální připravený tisk:** [nastavený projekt26 kusů](rozlozeni/kombinovana-03-2026-09-20/auticko-25-kombinovana-03-nastaveny-projekt.3mf), [číslovaný náhled](rozlozeni/kombinovana-03-2026-09-20/podlozka.png), [návod a ověření](rozlozeni/kombinovana-03-2026-09-20/README.md). Otevřít jako celý projekt, měřítko100 %, nic nekopírovat ani automaticky nerozmísťovat.

Úplný původní kusovník zůstává66 kusů ve skupinách26 /27 /13. Původní01 a02 jsou zachované záznamy již tištěných várek, ne pokyn k jejich opakování. Oba soubory jsou nyní uložené jako Next projekty s vypnutými podporami;01 má dřívější zachovaný hash,02 byla později přebalená s profilem0,20mm. Geometrie02 stále odpovídá původnímu manifestu27 kusů; konkrétní tištěný G-code tím není prokázán. [Přehled variant a zachování](rozlozeni/README.md).

- [Editovatelná sestava FreeCAD](auticko-silovy-prevod-25.FCStd).
- [Alternativa: kompletní ZIP s 66 jednotlivými STL kopiemi](tiskovy-balicek.zip). Každý soubor jednou; neimportovat současně sadu 3MF a ZIP.
- CAD náhledy: [rovně](rovne.png), [doleva](doleva.png), [doprava](doprava.png), [mechanismus](mechanismus.png), [rozložená sestava](rozlozena-sestava.png). Barvy rozlišují díly, nikoli filament.
- [Montážní návod](montaz.md), [rozměry a architektura](architektura.md), [strojový stav revize](stav-revize.json).
- Zdroj: [hlavní makro](auticko-silovy-prevod-25.FCMacro), [geometrie řízení](rizeni-geometrie.py), [uchycení serva](servo-uchyceni.py), [sestavení řízení](rizeni-sestava.py). Pro regeneraci ponechat všechny čtyři soubory vedle sebe. Uložený FCStd používá standardní editovatelné objekty a tabulky.

Vše se předává přímo v tomto projektu. Starší kopie na ploše se neaktualizují a nejsou touto revizí. [Předchozí dokončená varianta je archivovaná](historie/pred-kalibraci-8_6-12_6-2026-09-20/README.md). Nové mechanické díly nemíchat s původními V2/V3; použije se stávající motor, SG90, originální jednoramenná páčka a její středový šroubek.

## Rozměry spojů této revize

| Funkce | Návrhový rozměr v mm |
|---|---|
| Mezikola otočná na Ø8 čepech | Ø8,6 ve dvou 5mm vodicích pásmech; 20mm střed Ø9 |
| Pevné Ø8 čepy v rámu | Sedlo Ø8,1 |
| Zadní Ø12 osa otočná v rámu | Otvor Ø12,6 |
| Výstupní ozubené kolo na zadní ose | Samostatný otvor Ø12,1; moment přenáší příčný klíček |
| Zadní kola na D koncích osy | Kruhová část Ø12,1; ploška 4,05 od osy proti plošce osy 4,00 |
| Statické Ø4 zajišťovací čepy a klíček | Otvory Ø4,1 |
| Sedla plošiny | Ø8,1 |
| Přední otočné Ø8 spoje | Ø8,6, beze změny |
| Otočné Ø6 klouby táhel | Ø6,5, beze změny |
| Motorový pastorek | Otvor Ø2,2, beze změny |

Průměry nosných čepů a os se nezmenšovaly. Jiří na dřívějším vzorku potvrdil otáčení Ø8 čepu v otvoru 8,6 a vyhovující nasazení Ø12 do 12,6. Nejde o měření skutečné vůle celého nového auta. Nejmenší pevné otvory 8,1 / 12,1 / 4,1 jsou návrhová volba podle zadání; jejich fit nebyl fyzicky potvrzen. Při montáži je nesestavovat násilím.

## Co konstrukce obsahuje

Tři stupně **18→54, 18→60 a 22→55 dávají 25:1**. Původní modul 1 mm, úhel 20° a rozteče 36,4 / 39,4 / 38,9 mm zůstávají. Výstupní 8mm pastorek je vystředěný v 12mm věnci; při kontrolovaných axiálních krajních polohách zbývá rezerva 1,5 mm. Proti převodu 12:1 je ideální moment 2,083× při 48 % otáček, před ztrátami.

Mezikola běží na pevných oboustranně podepřených čepech se dvěma krátkými vodicími pásmy. Zadní osa má kruhové pracovní části a D konce pro kola. Pojistky drží polohu, nemají stahovat otočná čela. Všechna čtyři kola mají Ø76 × 12 mm a skutečný dezén; užitná plocha plošiny je 170 × 60 mm.

Řízení používá SG90 a originální páčku s uživatelem změřeným účinným poloměrem 15 mm. Ostatní rozměry konkrétní páčky a těla serva nejsou fyzicky ověřené. Nové mechanické spojovací díly jsou tištěné; návrh nevyžaduje nové M2 šrouby, ložiska ani osy. Elektrika serva zůstává samostatnou etapou.

## Dřívější uživatelský záměr ve sliceru

Aktuální kombinovaný projekt má ověřenou vrstvu0,12mm; následující odstavec zachycuje starší hlášení, nikoli jeho nastavení. Jiří dříve uvedl, že změnil běžnou výšku vrstvy z **0,20 na 0,08 mm** a horní povrch chce ponechat na standardním **Monotonic line**. Jde o jeho hlášení nastavení, nikoli o námi přečtené živé UI, osobní preset nebo hotový G-code. Potvrzení spuštění či dokončení tisku nové revize z něj neplyne.

Pokud toto nastavení ponechá, mechanické díly mají použít stejnou 0,08mm vrstvu a stejné ostatní nastavení. **První vrstva se tím automaticky nemění.** V místním systémovém profilu Kobra X 0,4 byl ověřen rozsah **0,08–0,28 mm**; Standard uvádí běžnou i první vrstvu **0,20 mm** a horní vzor `monotonicline`. Dokládá to [read-only záznam profilu](rozlozeni/profil-podlozky.json), nikoli kontrola neuloženého okna sliceru. Geometry-only 3MF obsahují pouze geometrii a rozmístění: výšku vrstvy, vzor povrchu, průtok, teploty ani osobní presety nepřepisují.

Nižší vrstva může zjemnit odstupňování oblých ploch ve směru Z; sama neopravuje XY průměry otvorů, tvar zubů, nesouosost ani neprokazuje nižší tření. Přepnutí mezi Rectilinear, Monotonic line a Archimedean chords není doložená oprava mechaniky; změna vzoru není součástí tohoto návrhu.

## Tiskové orientace a podpory

STL zachovávají původní exportní souřadnice; aktuální tiskové orientace třetí podložky a opravné sady určují jejich generátory a 3MF. Automatické otočení v nástroji Arrange může změnit povrchy, které se opírají o podpory; samotná kalibrace jiné orientace pak nemusí platit.

| Skupina | Orientace a co zkontrolovat ve skutečných vrstvách |
|---|---|
| Kola, výstupní kolo, motorový pastorek | Plochým čelem na podložku; u dezénu zkontrolovat drobné převisy a skutečné vyplnění špiček zubů |
| Dvojkola A/B | Velké ozubené čelo leží na podložce. Vyvýšené malé ozubení má spodní převisy: může potřebovat lokální podpory **na těle modelu**, pouze podpory z podložky nemusejí stačit |
| Kruhové čepy a zadní osa | Původní01/02 zůstávají historicky naležato. **Aktuální03 a opravy** mají čepy na hlavách a zadní osu svisle s lokálními podporami. Není to obecná záruka větší pevnosti; u 150,6mm osy zkontrolovat stabilitu, příčný otvor a pojistné drážky |
| Těhlice, čelisti a držáky | Původní export vyžaduje kontrolu osiček, ramen, kapes a vodorovných otvorů. **Pravá těhlice v dotisku** je nově otočená na oko/rameno, stále s podporami včetně podpor na modelu. Levá těhlice byla na nových fotografiích také vadná; obě jsou v kombinované26 otočené a se skutečnými podporami |
| Plošina | Horní plochou na podložku, nohy nahoru; u dvou zadních nohou je 2mm boční převis, který vyžaduje kontrolu lokální podpory. Zkontrolovat také příčné otvory v nohách |
| Rám | Dnem na podložku; zkontrolovat vodorovné otvory a místní převisy kolem vidlic, motoru a serva |
| Pojistky, táhla, podložky, objímka páčky | Zachovat export; zejména drážky víka objímky, malé pojistky a jejich oddělení od podpor vyžadují prohlídku vrstev |

Rozmístění samotných modelů ani jejich rezervy pro brim nedokazují prostor pro libovolné podpory. Před tiskem je potřeba prohlédnout skutečně vygenerované dráhy, případně zvětšit mezery. Nové nastavené projekty03 a opravné sady podpory obsahují a prošly kontrolou skutečných drah; geometry-only alternativy proces nemají. Projekty neobsahují G-code a místní řezání nepotvrzuje fyzický výsledek.

## Kusovník

<!-- BOM-BEGIN -->
**Kusovník: 34 různých typů, celkem 66 fyzických kusů.** Počty jsou odvozené ze skutečných montážních instancí uložené sestavy. Kompletní ZIP obsahuje každou kopii zvlášť; tabulka není pokyn k dalšímu násobení součástí ve sliceru.

| Typ STL | Počet | Místo v sestavě |
|---|---:|---|
| [mezikolo-a-54_18](stl/mezikolo-a-54_18.stl) |1 |U motoru; velké 54 a malé 18 zubů |
| [mezikolo-b-60_22](stl/mezikolo-b-60_22.stl) |1 |U zadní osy; velké 60 a malé 22 zubů |
| [vystupni-kolo-55](stl/vystupni-kolo-55.stl) |1 |Na zadní ose, zajištěné příčným klínkem |
| [pastorek-18-otvor-2_2](stl/pastorek-18-otvor-2_2.stl) |1 |Nový pastorek motoru; fit 2,2 znovu ověřit |
| [ram-25](stl/ram-25.stl) |1 |Společný rám s uložením pohonu i řízení |
| [pevny-cep-8x53_9](stl/pevny-cep-8x53_9.stl) |2 |Po jednom do každého mezikola |
| [pojistka-6_9](stl/pojistka-6_9.stl) |7 |2 pevné čepy +2 svislé čepy +2 přední kola +1 kloub páčky |
| [pricny-klinek-4x27_1](stl/pricny-klinek-4x27_1.stl) |1 |Spoj výstupního kola a zadní osy |
| [pojistka-3_1](stl/pojistka-3_1.stl) |10 |1 klínek osy +2 motor +4 plošina +2 servo +1 objímka páčky |
| [spolecny-cep-mustku-4x30_5](stl/spolecny-cep-mustku-4x30_5.stl) |2 |Dva dlouhé čepy pro oba motorové můstky |
| [cep-plosiny-4x19_5](stl/cep-plosiny-4x19_5.stl) |4 |Po jednom do každé nohy plošiny |
| [pojistka-osy-10_9](stl/pojistka-osy-10_9.stl) |4 |2 vnitřní zajištění zadní osy +2 zadní kola |
| [osa-zadni-12x150_6](stl/osa-zadni-12x150_6.stl) |1 |Kruhové pracovní plochy, D konce pro zadní kola |
| [rozperka-zadni-17_6](stl/rozperka-zadni-17_6.stl) |2 |Jedna na každé straně zadní osy |
| [kolo-76x12-zadni-d](stl/kolo-76x12-zadni-d.stl) |2 |Dvě poháněná zadní kola s D otvorem |
| [kolo-76x12-predni](stl/kolo-76x12-predni.stl) |2 |Dvě volně otočná přední kola |
| [motorovy-mustek](stl/motorovy-mustek.stl) |2 |Dva horní motorové třmeny |
| [motorovy-klinek](stl/motorovy-klinek.stl) |2 |Po jednom přítlačném klínku do každého můstku |
| [plosina-170x60](stl/plosina-170x60.stl) |1 |Plošina s užitnou plochou 170 × 60 |
| [servo-viko](stl/servo-viko.stl) |1 |Zachycení původních uší SG90 |
| [servo-cep-4x51_2](stl/servo-cep-4x51_2.stl) |2 |Dva čepy víka serva |
| [objimka-packy-spodek](stl/objimka-packy-spodek.stl) |1 |Spodní tvarové zachycení originální páčky |
| [objimka-packy-viko](stl/objimka-packy-viko.stl) |1 |Zasouvací víko s vlastním otočným čepem |
| [objimka-cep-4x25_5](stl/objimka-cep-4x25_5.stl) |1 |Zajištění spodku a víka objímky |
| [podlozka-packy-1_8](stl/podlozka-packy-1_8.stl) |1 |Distanční podložka pod oko servotáhla |
| [celist-horni](stl/celist-horni.stl) |2 |Jedna horní vidlice na každé straně řízení |
| [svisly-cep-8](stl/svisly-cep-8.stl) |2 |Dva svislé čepy řízení |
| [tehlice-leva](stl/tehlice-leva.stl) |1 |Levá otočná těhlice s osičkou předního kola |
| [tehlice-prava](stl/tehlice-prava.stl) |1 |Pravá otočná těhlice s osičkou předního kola |
| [spojovaci-tahlo](stl/spojovaci-tahlo.stl) |1 |Propojení obou ramen řízení, odsazení dopředu |
| [servo-tahlo-r15](stl/servo-tahlo-r15.stl) |1 |Propojení originální páčky s levým ramenem |
| [cep-tahla-dlouhy](stl/cep-tahla-dlouhy.stl) |1 |Levý kloub s oběma táhly |
| [cep-tahla-kratky](stl/cep-tahla-kratky.stl) |1 |Pravý kloub spojovacího táhla |
| [pojistka-kloubu-4_9](stl/pojistka-kloubu-4_9.stl) |2 |Po jedné pod každý kloub táhla |

**Přesně čtyři kola:** dvě přední a dvě zadní. Mezi opakované díly patří také všechny rozpěrky, podložky, čepy a pojistky. Původní motor, servo, jeho jednoramenná páčka a středový šroubek jsou referenční vlastněné součásti, netisknou se a nejsou v 66 kusech.
<!-- BOM-END -->

## Montáž a elektronika

[Montážní návod](montaz.md) rozlišuje zadní rozpěrky, klínek, zajištění motoru a řízení. **Mezikolo B → motor, můstky a jejich oba dlouhé čepy → mezikolo A.** Po nasazení A už levý motorový čep nelze přímo zasunout.

Po očištění výtisků zkus jednotlivá uložení a pak postupně celé otáčky převodů. Při tvrdém místě se vrať k poslednímu přidanému dílu; nepřemáhej převod motorem. Doplňkové [kalibrační vzorky](kalibrace/README.md), [Ø4 V2](kalibrace-4-v2/README.md) a [ruční zkouška převodu](zkouska-prevodu/README.md) jsou zachované jako volitelné podklady, nikoli povinná podmínka tisku této sady.

Aktuální zapojení a fyzické zkoušky ovládání jsou v [elektronice autíčka](../../elektronika/auticko/README.md), vybavení v [inventáři](../../elektronika/vybaveni.md). Tato revize firmware ani zapojení nemění. Tři vnější záběry obracejí směr výstupu proti motoru; první elektrickou zkoušku provést s koly nad podložkou. Přepojovat pouze bez napájení.

## Co je ověřené

- [Kontrola aktuální revize](kontrola-revize-fitu.json): nominální sestava bez nepovolených průniků, shoda šesti původních ozubených obrysů s archivem, změněné otvory, relevantní krajní polohy objímky a celá 8mm šířka posledního záběru s rezervou 1,5 mm.
- [Souhrn CAD a parametrů](kontrola-modelu.json) a [GUI](kontrola-gui.json): vazba na zdroj, platná tělesa, uložená a znovu otevřená sestava a nové skutečné náhledy.
- [Nezávislá kontrola zdroje a původu důkazů](nezavisla-kontrola-revize.json): konkrétní aktuální FCStd a zdroje, archiv a explicitní rozsah převzatých kontrol nezměněného ozubení/řízení. Staré kontroly se nevydávají za nový průchod všech kombinací vůlí.
- [Exportní kontrola](overeni-exportu.json): všech 34 uzavřených STL, 66 fyzických kopií, čtyři kola, shoda ZIP/3MF/kusovníku, rozmístění a import/export Anycubic Slicer Next. [Podrobnosti podložek](rozlozeni/README.md).

**Hranice výsledku:** `nominal_cad_validation_pass=true` se vztahuje k nominální geometrii autorizovaného tiskového prototypu. `full_nominal_radial_clearance_scenario_pass=false` zůstává přiznané: kdyby celé nominální rozdíly průměrů tvořily reálnou provozní vůli, původní záběr tento rozsah nepokrývá. Skutečná vůle zatím není změřená. První várka je nyní doložená fotkami s vadami, druhá se tiskne; montáž, souvislý chod pod zatížením, trakce a životnost zůstávají neověřené. Původní celá sada neobsahuje nastavení podpor; samostatný dotisk má vlastní návod a kontrolu skutečných drah.

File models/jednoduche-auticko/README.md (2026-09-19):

# Jednoduché autíčko s jedním motorem

Zadání uživatele z 19. 9. 2026. **Stav: parametrický prototyp geometricky zkontrolovaný, pastorek vytištěný a nasazený, první stolní rozběh motoru tlačítkem z telefonu potvrzený uživatelem.** Fyzická montáž podvozku a jízda nejsou ověřené. Podle zkoušky otvoru označeného **2,2 mm** byl upraven **[pastorek pro slicer](stl/pastorek.stl)**, zdrojové makro i sestava; uživatel potom potvrdil dobré nasazení hotového pastorku na motor. Tisk dalších 13 kusů z devíti typů STL zadal s odhadem sliceru **3 h 15 min**. Dokončení tisku a přenos momentu při zátěži ještě nepotvrdil.

## Kde pokračovat po dnešní práci

- **[Nová snímatelná horní plošina](strecha.md)** — rovná užitná plocha **170 × 60 mm** pro pole podle zadání uživatele. Nasazuje se na čtyři stávající výstupky u kol; podvozek se netiskne znovu. [Nové STL — 1 kus](stl/strecha.stl), [sestava ve FreeCADu](auticko-se-strechou.FCStd), [náhled](strecha-sestava.png). Dokončení tisku a nasazení potvrdil uživatel; správný dosed, provozní vůle a nosnost neověřeny.
- **[Záznam prvního stolního testu](../../elektronika/auticko/prvni-stolni-test.md)** — co jsme sestavili, co se skutečně podařilo, fotografie, opravy a poslední stav. Motor po tlačítku běžel asi sekundu; po vyjmutí jedné AA už neběžel. Napájení bylo provizorní, bez kondenzátorů a s dočasnými motorovými kontakty.
- **[Elektronika autíčka — aktuální stav](../../elektronika/auticko/README.md)**; [historie zprovoznění](../../elektronika/auticko/elektronika.md), [tabulka zapojení L293D](../../elektronika/auticko/zapojeni-l293d.md), [firmware](firmware/prvni-motor/README.md) a [inventář vybavení](../../elektronika/vybaveni.md).
- **[Oprava ovládání při držení](../../elektronika/auticko/README.md)** — `hold-to-run-v2` je přeložené, otestované a nahrané; požadavek rollbacku uživatel odvolal před uploadem. [Firmware](firmware/prvni-motor/README.md) uvádí skutečný stav nahrání a testů, [záznam potíží](../../elektronika/auticko/potize-po-montazi.md) zachovává historii a omezení fyzického ověření.
- [Deník tisků](../../docs/denik-tisku.md), [balíček zbývajících 13 dílů](zbytek-auticka.zip) a montážní pořadí níže.

## Výsledek zkoušky hřídelky — otvor 2,2 mm

Původní vzorek Ø 0,9–1,3 mm podle uživatele nevyhověl: ani největší otvor nelze nasunout. Kontrola původního STL potvrdila průchozí otvor Ø 1,3 mm, takže export odpovídá původnímu návrhu. Skutečný průměr hřídelky, rozměry vytištěných otvorů ani příčina rozdílu zatím nejsou známé. Požadavek „aspoň dva“ znamená větší zkušební otvory, ne nové přesné měření hřídelky.

Na výslovné přání uživatele je vzorek nyní nižší: **54 × 48 × 2 mm**. Má devět průchozích otvorů a zapuštěná čísla o hloubce 0,6 mm. Čísla označují **nominální průměr v CADu**. Slouží jen k rychlé zkoušce vstupu hřídelky; otvor pastorku je dlouhý **5,5 mm**, takže průchod krátkým vzorkem ještě nepotvrzuje fit po celé délce pastorku ani přenos momentu.

| Spodní řada při čtení číslic | Prostřední řada | Horní řada |
|---|---|---|
| 1,8 / 2,0 / 2,2 mm | 2,4 / 2,6 / 2,8 mm | 3,0 / 3,5 / 4,0 mm |

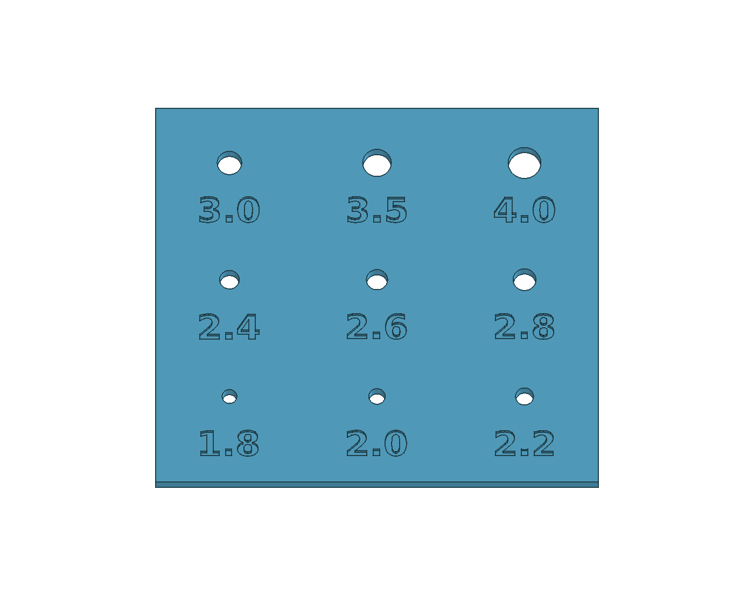
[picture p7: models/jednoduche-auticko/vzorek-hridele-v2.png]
Skutečný CAD náhled většího vzorku


- Historický export pro Anycubic Slicer Next měl cestu `stl/vzorek-hridele-v2.stl`; při uložení tohoto zápisu soubor v checkoutu chybí. Zachovaný je [zdrojový FreeCAD model](vzorek-hridele-v2.FCStd) a makro níže. Pokud by bylo později potřeba STL obnovit, znovu jej exportovat a ověřit. Původní tiskový postup: měřítko **100 %**, rovnou spodní stranou dolů, číslicemi nahoru, rozměry 54 × 48 × 2 mm. Nyní vzorek znovu tisknout není potřeba.
- [Editovatelný FreeCAD model](vzorek-hridele-v2.FCStd), [zdrojové makro](vzorek-hridele-v2.FCMacro), [kontroly](kontrola-vzorku-v2.json) a [makro skutečného náhledu](nahled-vzorku-v2.FCMacro).
- Ve sliceru zkontrolovat, že jsou všechny otvory průchozí a číslice čitelné; geometrie nevyžaduje podpory. Tiskový profil ani nové G-code zatím nejsou ověřené.
- Na vychladlém výtisku zkoušet jemně **od největšího otvoru k menším**. Zapsat číslo otvoru, který jde nasunout těsně bez násilí, a zda má vůli nebo se protáčí. Těsný fit ještě sám nedokazuje přenos momentu při jízdě.

**Ověření při vytvoření vzorku:** jeden platný solid, všech devět otvorů průchozích a tehdejší STL po znovunačtení uzavřené v jedné komponentě. Tloušťka 2 → 2,5 → 2 mm přepočítala i polohu číslic a vrátila původní objem. PNG byl vizuálně zkontrolovaný; uložený FCStd zobrazuje pouze finální objekt `Coupon`, pomocné tvary jsou skryté. Tyto výsledky nezaměňovat za novou kontrolu nyní chybějícího STL.

**Fyzický výsledek, hlášení uživatele:** hřídelka motoru se vejde do otvoru označeného **2,2 mm**. To je zvolený nominální průměr otvoru v CADu, nikoli změřený průměr hřídele. Později uživatel vytiskl také hotový pastorek a potvrdil, že na motor krásně pasuje. Skutečný rozměr otvoru a přenos momentu při zatížení nebyly změřeny. Přesná verze výšky vytištěného vzorku a tiskový profil nebyly doloženy; původní odeslání souboru proto zpětně nepřiřazujeme k určité výšce. Vzorek už není nutné znovu tisknout.

V2 je samostatný dokument a makro. Průměry při změně upravit v `DIAMETERS` a spustit makro znovu, aby se obnovila také čísla. FCStd obsahuje běžné objekty a výrazy; obrysy číslic jsou uložené přímo, takže otevření modelu nevyžaduje font ani vlastní Python třídu. Regenerace písma používá DejaVu Sans Bold uvedený ve zdroji. Makro autíčka nadále vytváří historický vzorek v1; v2 nepřepisuje. Aktuální sestava a pastorek mají otvor **2,2 mm**. Netisknutelná reference hřídelky má pro náhled také 2,2 mm; jde o vizualizaci zvoleného otvoru, nikoli nové měření skutečné hřídele.

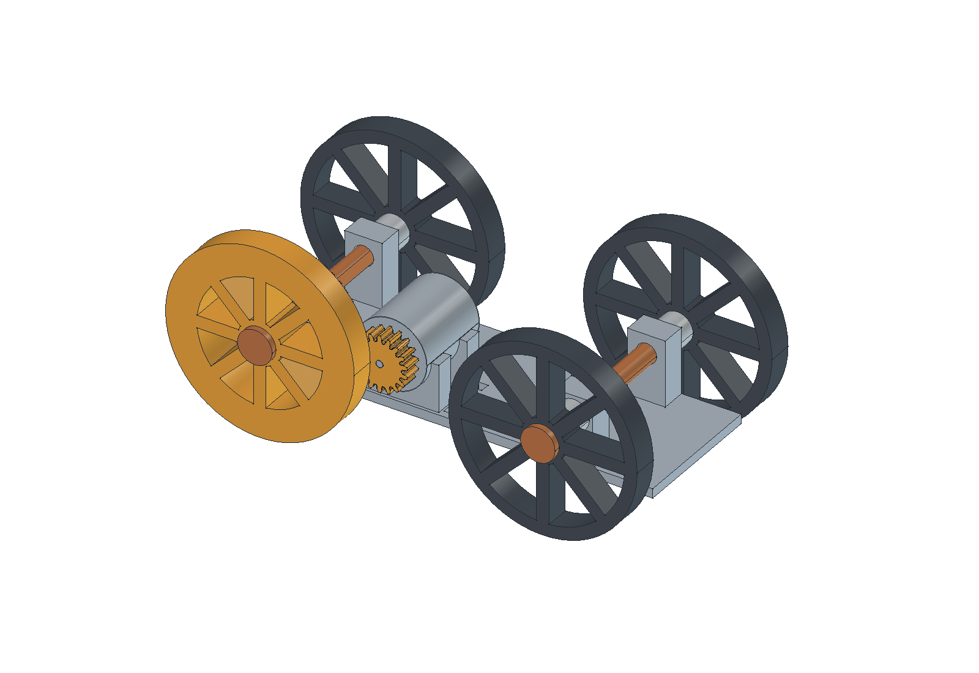
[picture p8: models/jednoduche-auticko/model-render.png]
Skutečný CAD náhled sestavy


Barvy v náhledu pouze rozlišují součásti. Šedý motor je netisknutelná rozměrová reference; kontakty nebyly rozměrově zadané, a proto nejsou vymyšlené ani modelované. Stahovací pásky nejsou součástí náhledu ani STL.

## Potvrzené zadání

- Uživatel má jeden motor; označení a elektrické parametry zatím neuvedl. Jeho ruční měření je níže.
- Co nejjednodušší tisknutelná konstrukce: platforma pro motor, čtyři kola a ozubený převod pohánějící zadní kola.
- Původní mechanický požadavek je pohyb dopředu a dozadu podle směru motoru. Pro první elektronickou zkoušku uživatel později zjednodušil ovládání na jedno tlačítko a jeden směr. Řízení zatáčení není součástí zadání.
- Parametrický zdroj, STL jednotlivých dílů a skutečný CAD náhled budou uloženy zde podle [workflow projektu](../../docs/workflow.md).

## Motor — údaje potvrzené uživatelem

| Údaj | Poslední upřesněná hodnota | Původ |
|---|---:|---|
| Válcové tělo — průměr | 22,5 mm | Ruční měření uživatele a následné potvrzení kulatého těla |
| Délka těla bez hřídelky | 26 mm | Ruční měření uživatele |
| Délka přední vyčnívající hřídelky | 6 mm | Ruční měření uživatele |
| Průměr přední hřídelky | Skutečný průměr nezměřen; pro otvor zvoleno 2,2 mm | Původní odhad 1 mm neodpovídal zkoušce; uživatel následně potvrdil nasazení do vzorku označeného 2,2 mm |
| Napájecí kontakty | Dva, na zadní straně | Popis uživatele |

Přesnost měření nebyla ověřena. Tělo uživatel výslovně potvrdil kulaté. Hřídelka je v prvním návrhu uvažována jako kruhová; případná ploška jejího průřezu nebyla výslovně potvrzena. Motor podle těchto rozměrů automaticky nepřiřazovat ke konkrétnímu obchodnímu typu.

Držák musí ponechat přístup k oběma zadním kontaktům a místo pro vodiče; zadní čelo motoru neuzavřít. Vepředu musí být možné zasunout hřídelku do náboje hnacího ozubeného kola nebo spojení s jeho osou a přenášet krouticí moment. Způsob spojení se určí podle skutečného průměru a tvaru hřídelky, ne pouhým volným otvorem.

## Navržená koncepce — dosud neověřená

Jednoduchý rám, volně otočná přední kola a společná poháněná zadní náprava. Motorová hřídel bude rovnoběžná se zadní nápravou, aby mohl motor přes čelní ozubená kola otáčet zadní nápravou. Kola a ozubení musí být se svými poháněnými osami mechanicky spojená, nikoli pouze volně nasunutá. Nápravy potřebují podpory a zajištění proti bočnímu posuvu.

První varianta používá jako **návrhový experiment převod 3 : 1**, malé kolo 18 a velké 54 zubů, modul 0,9 mm a úhel záběru 20°. Návrhová osová vzdálenost 32,6 mm zahrnuje 0,2 mm navíc oproti jmenovitým 32,4 mm. Nejde o vyzkoušené tiskové vůle ani o převod zvolený podle změřených otáček motoru. Velké ozubené kolo je součástí levého zadního kola, aby sestava měla méně dílů.

Rám, čtyři kola, osy, distanční kroužky, pojistky a pastorek budou tisknutelné. Zadní osa má průběžnou D plošku, aby šla zadní kola nasunout a přenášela moment. V uložení ji vede zbývající válcová plocha; reálné tření, vůle a odolnost tištěné osy vyžadují zkoušku. Přední kola mají kruhové otvory pro volné otáčení.

**Netištěné součásti pro tuto variantu:** skutečný motor, dvě malé stahovací pásky pro jeho upevnění a vhodné napájení/vodiče. Vlastnictví pásek nebylo potvrzeno. Pro ovládání z prohlížeče už uživatel sestavil Arduino UNO R4 WiFi, ST L293D a motor a potvrdil krátký stolní rozběh. Skutečné provizorní napájení, kontakty a další postup jsou v [záznamu zkoušky](../../elektronika/auticko/prvni-stolni-test.md). Pásky vedou přes motor a svislými otvory skrz základnu, aby pod sedly nevznikal obtížně tisknutelný dlouhý tunel.
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

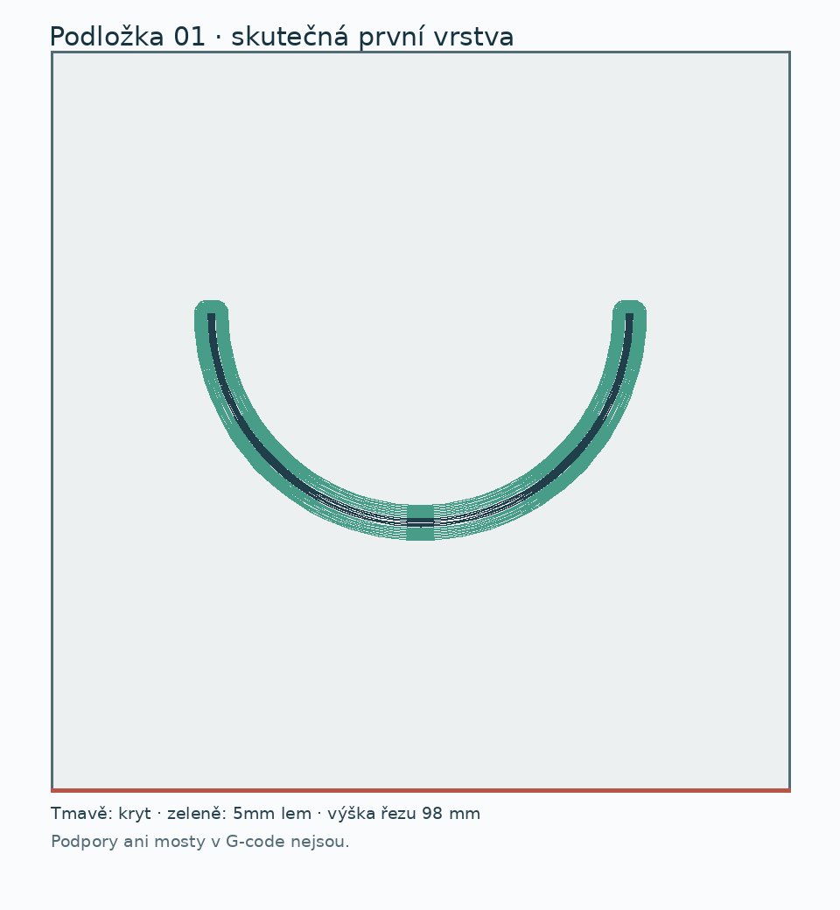
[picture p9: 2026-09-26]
models/kryt-trubky-digestore/rozlozeni/prvni-vrstva-01.png

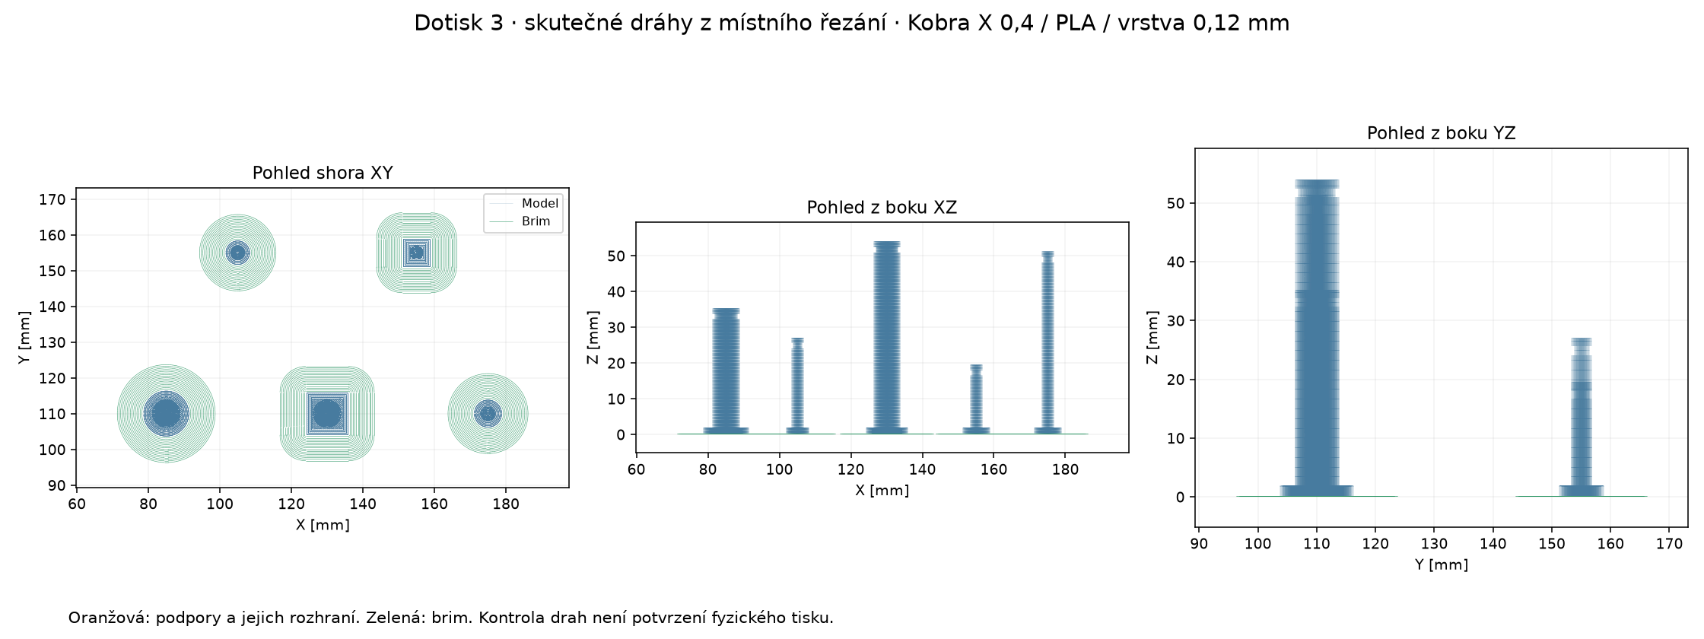
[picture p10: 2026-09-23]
models/auticko-silovy-prevod-25/rozlozeni/dotisk-prvni-varky-2026-09-20/evidence/drahy-03.png

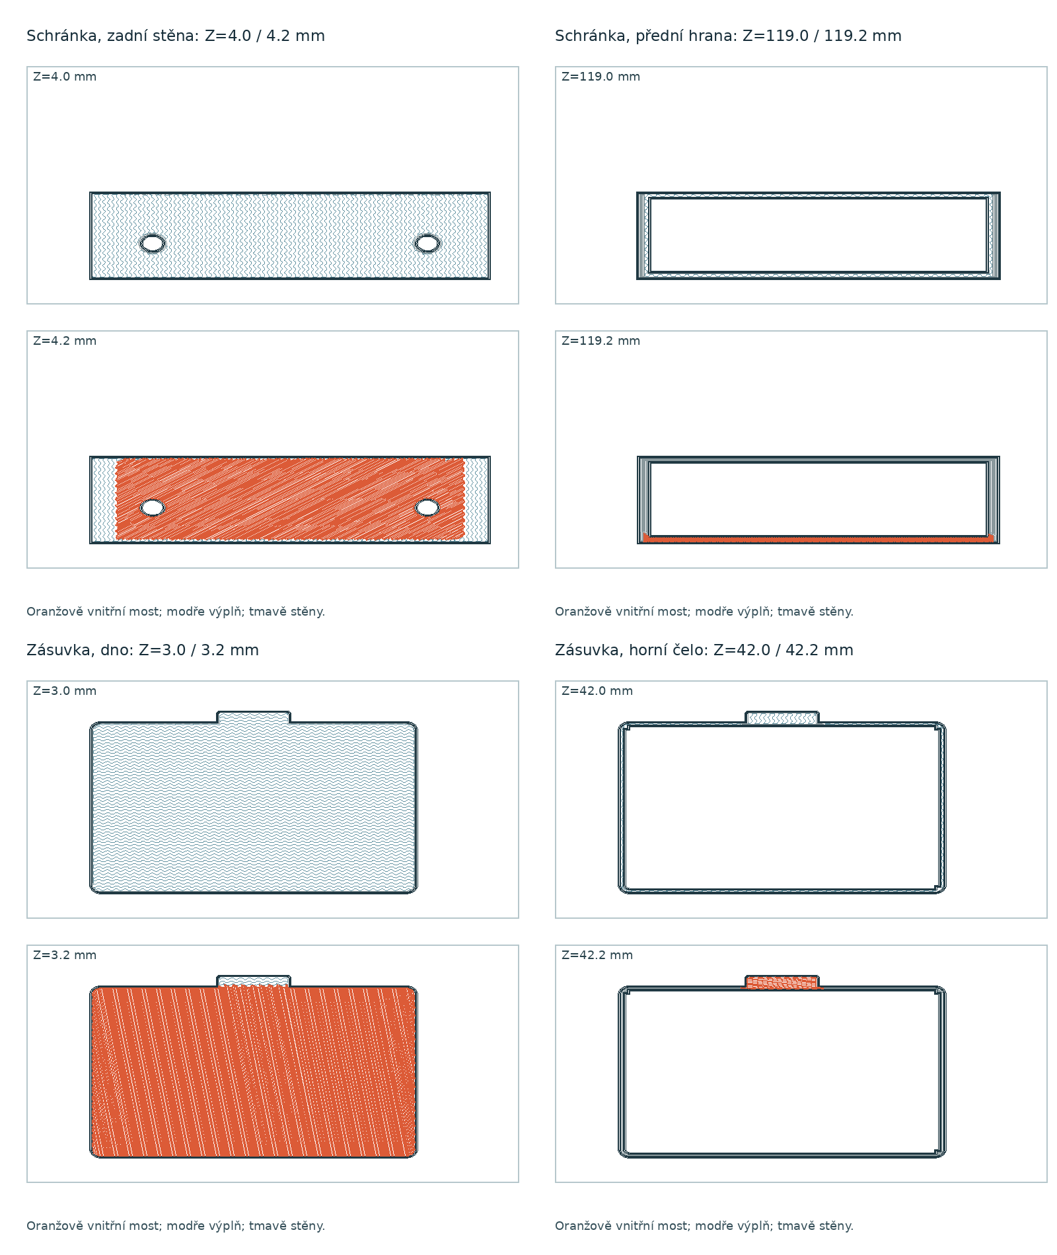
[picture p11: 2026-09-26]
models/drzak-toaletniho-papiru-s-prihradkou/rozlozeni/kriticke-vrstvy.png

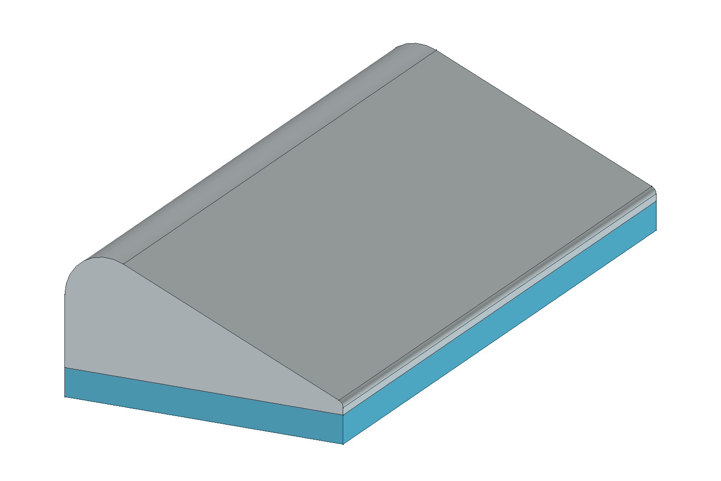
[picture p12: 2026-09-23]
models/koupelnova-prepazka/revize-02-8mm/profil-B-cad.png

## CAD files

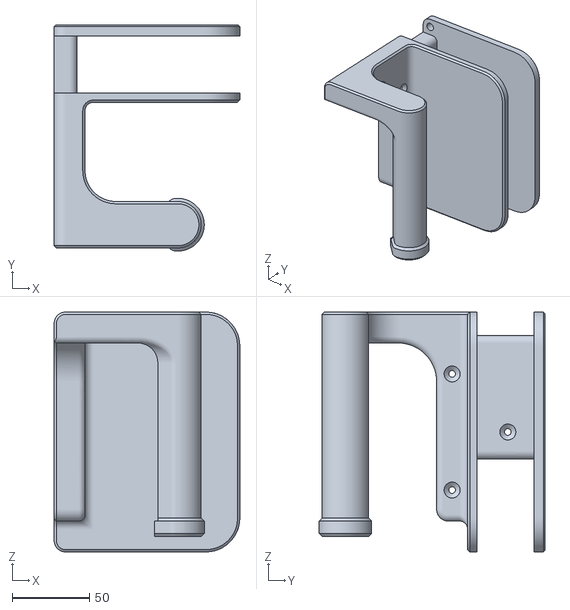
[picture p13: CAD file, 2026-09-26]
models/compartment_toilet_paper_holder/Main.stl
120.0 x 146.0 x 155.0

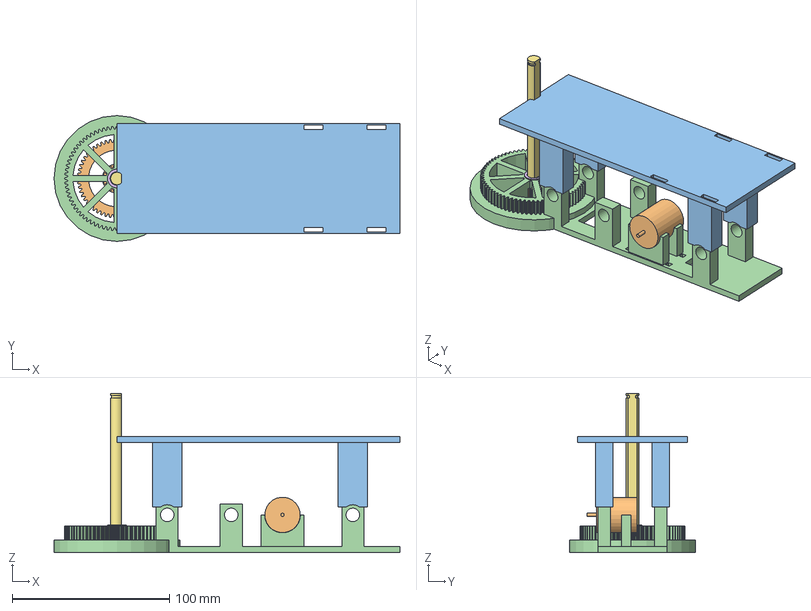
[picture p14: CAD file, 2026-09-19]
models/auticko-s-prevodovkou/auticko-s-prevodovkou.FCStd
220.0 x 80.0 x 101.3 mm
Pružná C pojistka — návrhový fit
Mezikolo 54 + 18 zubů v jednom dílu
Snímatelná plošina: užitná plocha 170×60
Rám 180 × 44 se šesti uloženími
Přední volné kolo, kruhový otvor
Dlouhá rozpěrka 17,6 mm
Hlavní D osa Ø8, 101,3 mm
Meziosa Ø8, 65,2 mm
Meziosa: rozpěrka 1,6 mm
MOTOR — pouze známé rozměry, bez nezměřených kontaktů
Pastorek 18 zubů, otvor 2,2 mm
Zadní levé kolo Ø80 + 72 zubů
Zadní pravé kolo, D otvor
Zadní levá rozpěrka 8,6 mm

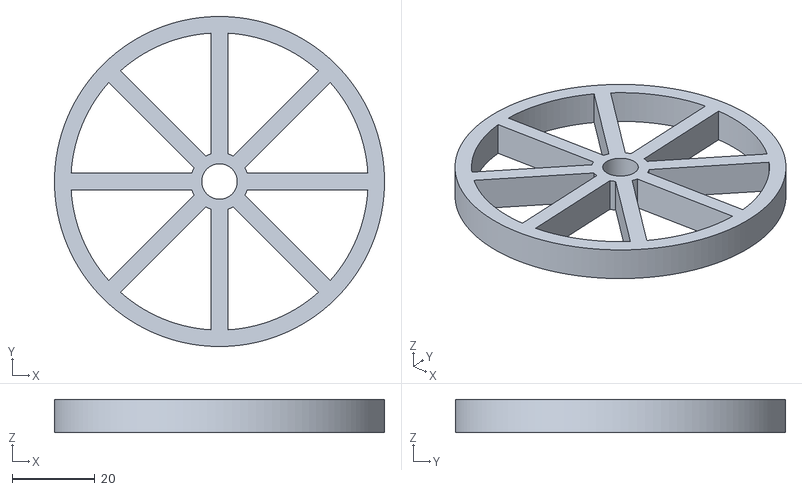
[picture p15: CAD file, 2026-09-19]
models/auticko-s-prevodovkou/stl/kolo-predni.stl
80.0 x 80.0 x 8.00

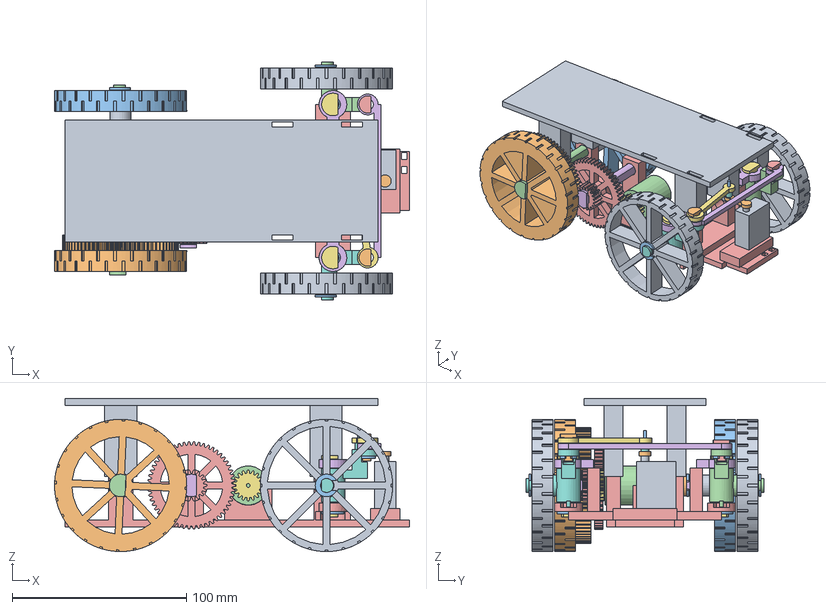
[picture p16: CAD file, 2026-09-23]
models/auticko-se-zatacenim/auticko-se-zatacenim.FCStd
204.0 x 136.6 x 88.0 mm
Snímatelná plošina: užitná plocha 170×60
TreadWheelRear
TreadWheelRight
Hlavní D osa Ø8, 101,3 mm
Mezikolo 54 + 18 zubů v jednom dílu
Meziosa Ø8, 65,2 mm
Pastorek 18 zubů, otvor 2,2 mm
Zadní levá rozpěrka 8,6 mm
Dlouhá rozpěrka 17,6 mm
Meziosa: rozpěrka 1,6 mm x 2
Pružná C pojistka — návrhový fit x 6
MOTOR — pouze známé rozměry, bez nezměřených kontaktů
SteeringFrame
ForkCap x 2
Kingpin x 2
KnuckleL
TreadWheelFront x 2
JointPinLong
SmallClip x 2
KnuckleR
JointPinShort
TieBar
DragLink
HornSpacer
SG90 — nominální reference, fit těla/páčky NEOVĚŘEN
HornReference
M2×16 reference — koupit/ověřit, netisknout

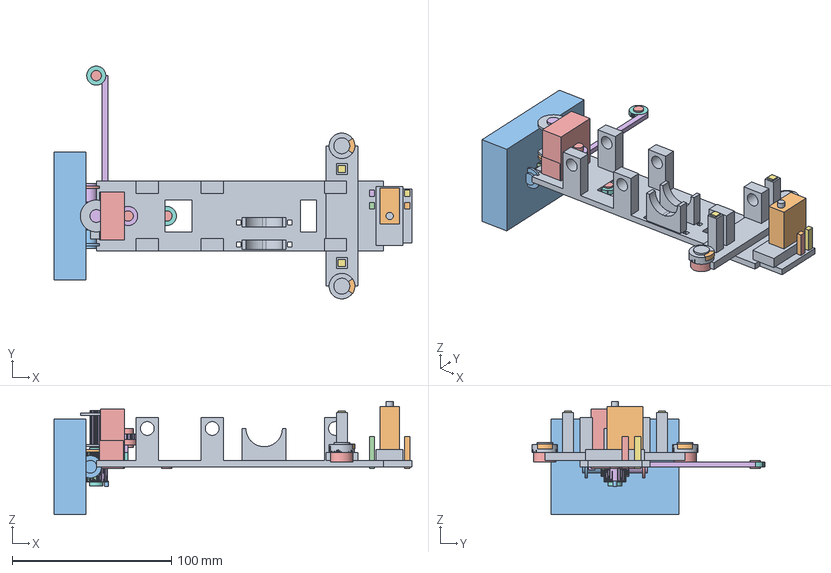
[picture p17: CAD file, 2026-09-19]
models/auticko-se-zatacenim/historie/pracovni-80x8/auticko-se-zatacenim.FCStd
224.5 x 146.0 x 71.0 mm
FrontCrossmember
NosePlate
LowerForkL
KingpinBoreL
ClipAccessL
ForkSupportL
CapRegisterVoidL
StopSectorL
StopInnerL
StopPocketL
LowerForkR
KingpinBoreR
ClipAccessR
ForkSupportR
CapRegisterVoidR
StopSectorR
StopInnerR
StopPocketR
ServoPedestal
ServoStrap50_1
ServoStrap501
ServoStrap85_1
ServoStrap851
ServoStrapBase
SteeringFrameMaterial
SteeringFrameVoids
SteeringFrame
CapEye
CapBridge
CapKey
CapMaterial
CapHole
ForkCap
KingpinRod
KingpinHead
KingpinBlank
KingpinFlatTool
KingpinFlat
KingpinGrooveOuter
KingpinGrooveCore
KingpinGroove
Kingpin
StubL
WheelCollarL
KnuckleBodyL
ArmBaseL
ArmRiseL
ArmEyeL
StopPegL
KnuckleMaterialL
KnuckleFlatToolL
KnuckleFlatL
StubGrooveOuterL
StubGrooveCoreL
StubGrooveL
KnucklePivotHoleL
ArmJointHoleL
JointClipAccessL
KnuckleVoidsL
KnuckleL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

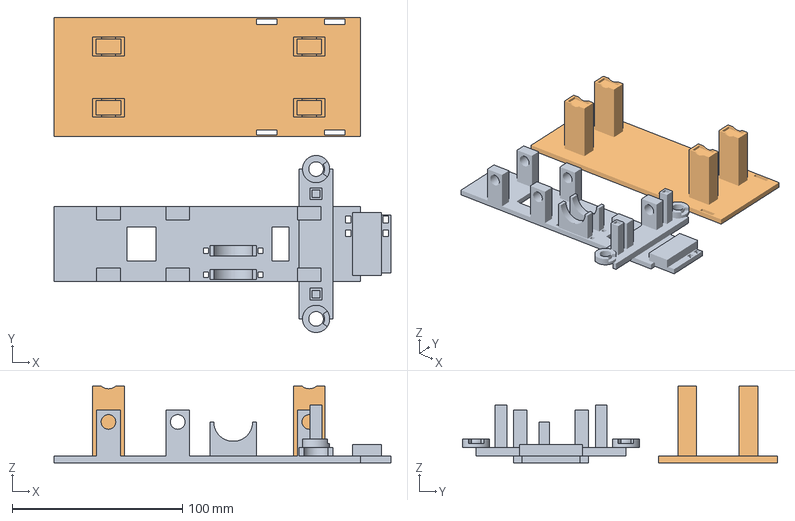
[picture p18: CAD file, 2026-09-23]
models/auticko-se-zatacenim/rozlozeni/auticko-v3-podlozka-02.3mf
198.0 x 185.0 x 45.0 mm
ram-rizeni__01
plosina-170x60__01

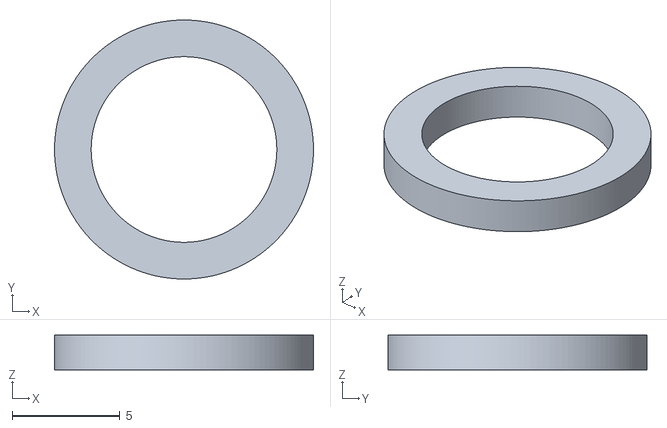
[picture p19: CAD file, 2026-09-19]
models/auticko-se-zatacenim/stl/rozperka-1_6.stl
12.0 x 12.0 x 1.60

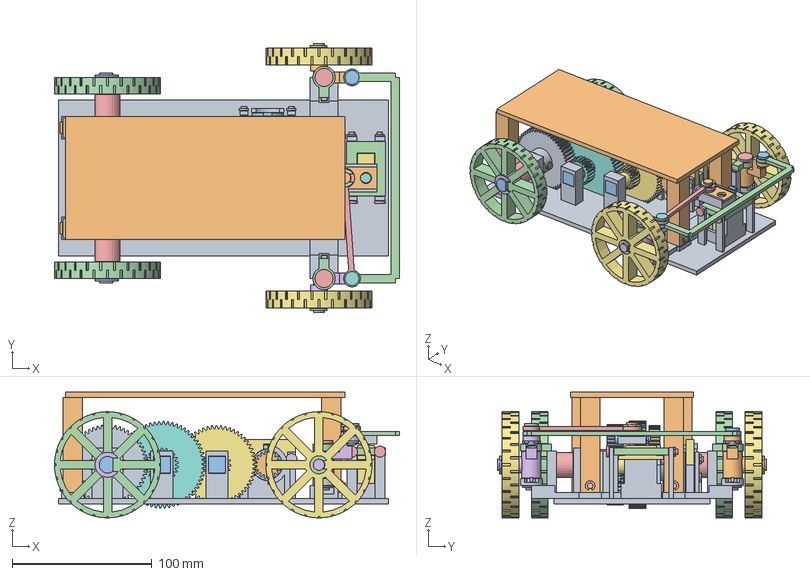
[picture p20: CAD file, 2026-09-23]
models/auticko-silovy-prevod-25/auticko-silovy-prevod-25.FCStd
247.0 x 192.6 x 90.0 mm
ram 001
plosina 170x60
osa zadni 12x150_6
kolo 76x12 zadni d x 2
rozperka zadni 17_6 x 2
pojistka osy 10_9 x 4
mezikolo a 54_18
mezikolo b 60_22
vystupni kolo 55
pastorek 18 otvor 2_2
pevny cep 8x53_9 x 2
pojistka 6_9 x 7
pricny klinek 4x27_1
pojistka 3_1 x 10
motorovy mustek x 2
motorovy klinek x 2
spolecny cep mustku 4x30_5 x 2
cep plosiny 4x19_5 x 4
MOTOR — reference, kontakty neměřeny
celist horni x 2
svisly cep 8 x 2
tehlice leva
kolo 76x12 predni x 2
cep tahla dlouhy
pojistka kloubu 4_9 x 2
tehlice prava
cep tahla kratky
spojovaci tahlo
servo tahlo r15
podlozka packy 1_8
SG90 — nominální reference, fit těla/páčky NEOVĚŘEN
HornReferenceMaterial
objimka packy spodek
objimka packy viko
objimka cep 4x25_5
servo viko
servo cep 4x51_2 x 2

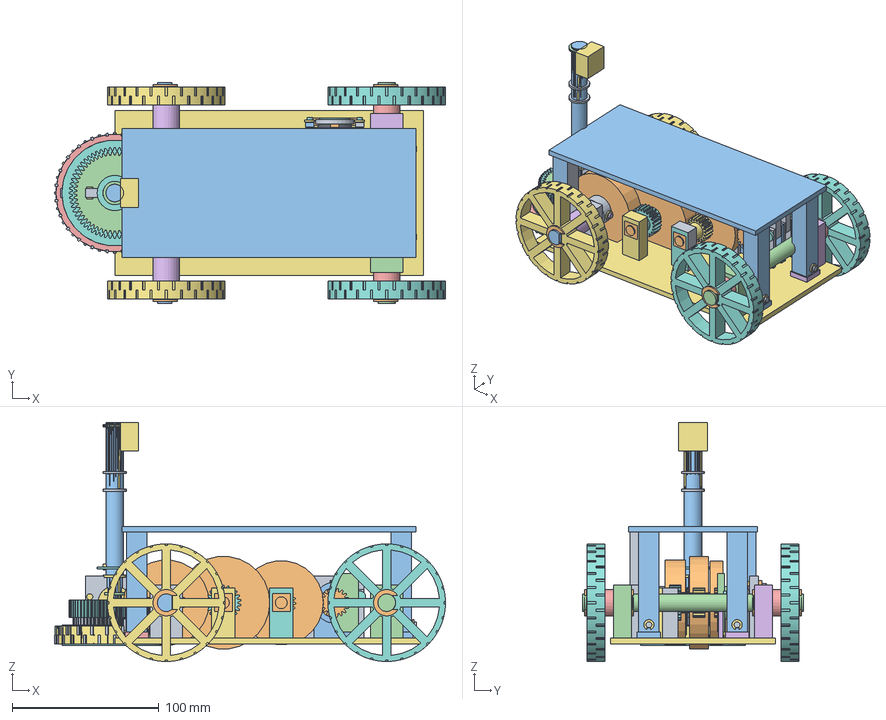
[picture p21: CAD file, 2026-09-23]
models/auticko-silovy-prevod-25/historie/pevny-predni-checkpoint/auticko-silovy-prevod-25.FCStd
266.0 x 150.6 x 162.6 mm
A54
A18
AHub
CompoundAMaterial
AJournalHoleThrough
AJournalHoleRelief
AJournalHole
B60
B22
BHub
CompoundBMaterial
BJournalHoleThrough
BJournalHoleRelief
BJournalHole
Output55
OutputHub
OutputMaterial
OutputBore
OutputCrossHole
OutputVoids
Input18
PinionBore
BasePlate
RearBearing1
RearBearingHole1
RearBearing3
RearBearingHole3
FrontBearing1
FrontBearingHole1
FrontBearing3
FrontBearingHole3
APinSupport1
APinSeat1
APinSupport3
APinSeat3
AThrustBoss
AThrustBossBore
AHeadKeyPocket
BPinSupport1
BPinSeat1
BPinSupport3
BPinSeat3
BThrustBoss
BThrustBossBore
BHeadKeyPocket
FloorClearanceA
FloorClearanceB
FloorClearanceO
MotorLower0
MotorSaddleBore0
MotorSaddle0
MotorBottomContact0
MotorEar011
MotorLockBore011
MotorEar013
MotorLockBore013
MotorEar031
MotorLockBore031
MotorEar033
MotorLockBore033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

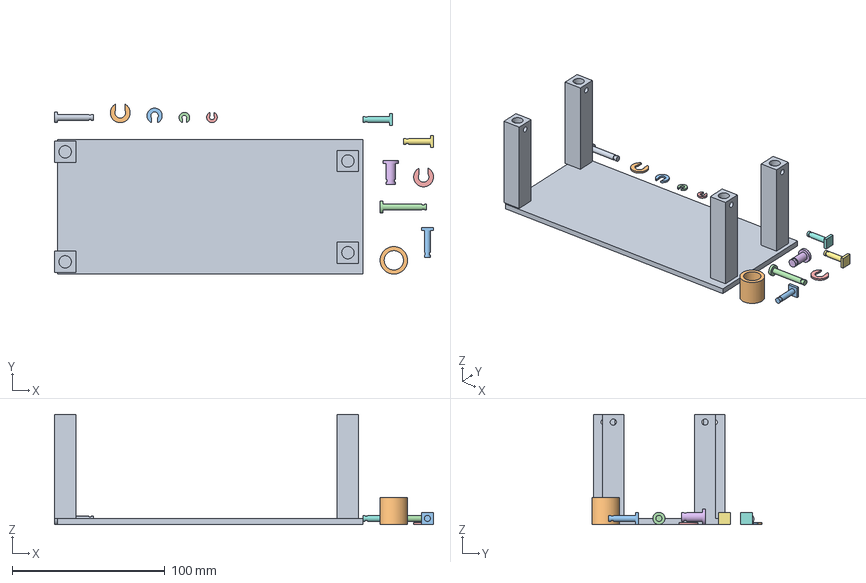
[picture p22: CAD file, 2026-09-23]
models/auticko-silovy-prevod-25/historie/pred-stojatou-orientaci-2026-09-20/auticko-25-podlozka-03.3mf
248.0 x 111.3 x 72.0 mm
plosina-170x60__01
rozperka-zadni-17_6__01
cep-plosiny-4x19_5__01
spolecny-cep-mustku-4x30_5__02
pojistka-6_9__03
cep-tahla-dlouhy__01
cep-plosiny-4x19_5__03
cep-plosiny-4x19_5__02
objimka-cep-4x25_5__01
pojistka-6_9__02
pojistka-kloubu-4_9__01
pojistka-3_1__08
pojistka-3_1__04

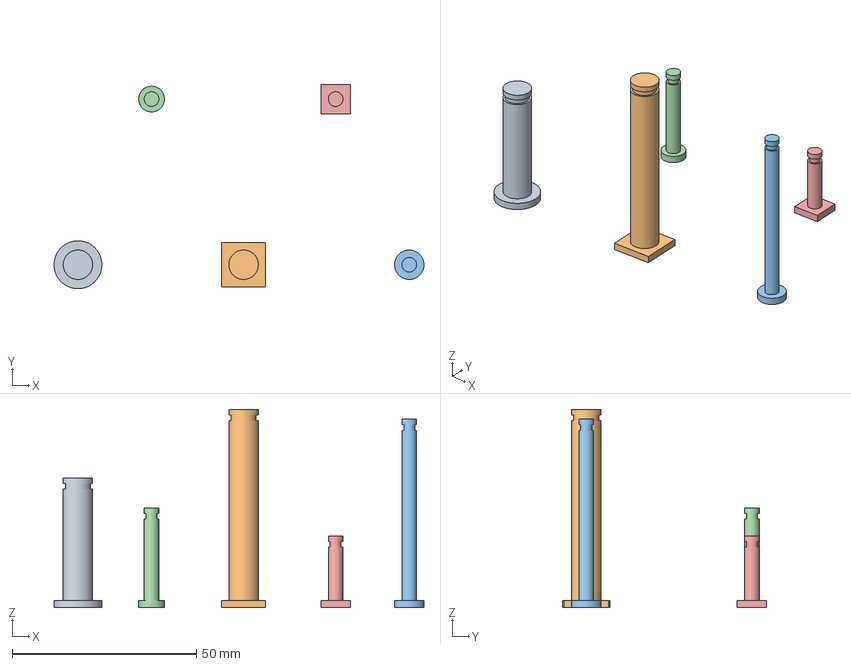
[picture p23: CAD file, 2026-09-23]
models/auticko-silovy-prevod-25/historie/pred-stojatou-orientaci-2026-09-20/dotisk-prvni-varky/dotisk-25-podlozka-03.3mf
100.5 x 55.5 x 53.9 mm
svisly-cep-8__02
pevny-cep-8x53_9__01
servo-cep-4x51_2__01
pricny-klinek-4x27_1__01
cep-plosiny-4x19_5__04

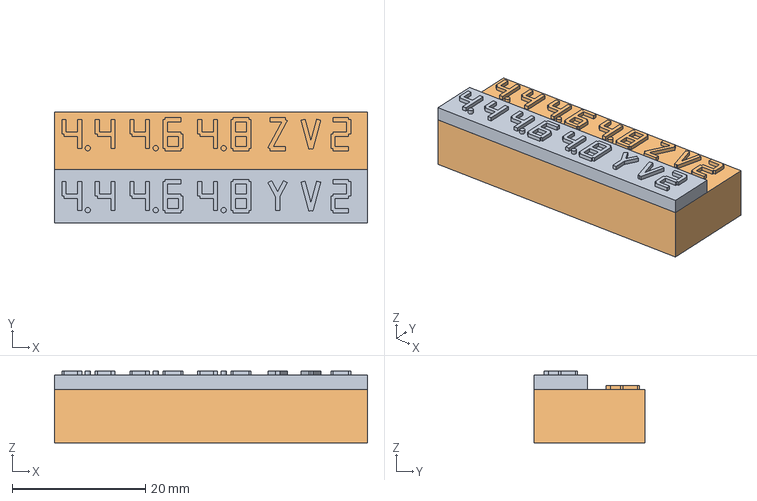
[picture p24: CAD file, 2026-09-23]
models/auticko-silovy-prevod-25/kalibrace-4-v2/kalibrace-4-v2.FCStd
47.0 x 16.6 x 10.8 mm
kalibrace-4-v2-y — 4.4 / 4.6 / 4.8
kalibrace-4-v2-z — 4.4 / 4.6 / 4.8

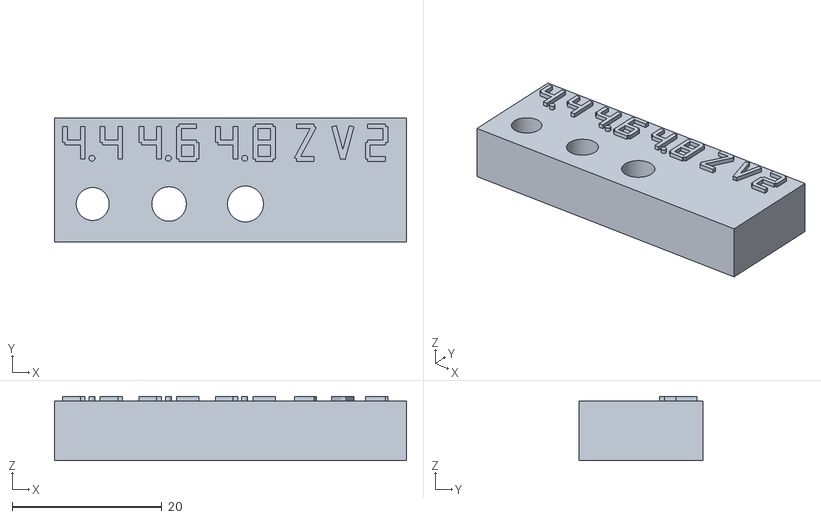
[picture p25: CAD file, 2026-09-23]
models/auticko-silovy-prevod-25/kalibrace-4-v2/stl/kalibrace-4-v2-z.stl
47.0 x 16.6 x 8.60

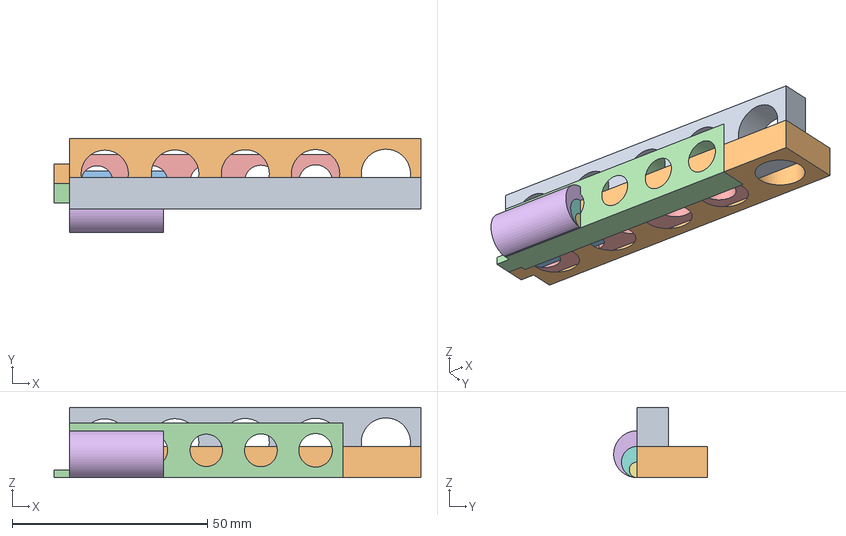
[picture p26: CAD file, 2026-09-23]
models/auticko-silovy-prevod-25/kalibrace/kalibrace.FCStd
94.0 x 24.0 x 18.0 mm
otvory-12-vodorovne
otvory-12-svisle
otvory-4-svisle
otvory-8-vodorovne
otvory-8-svisle
cep-12-kulaty-nalezato
cep-4-kulaty-nalezato
cep-8-kulaty-nalezato

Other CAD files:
models/auticko-silovy-prevod-25/historie/pred-stojatou-orientaci-2026-09-20/dotisk-prvni-varky/projekty-next/dotisk-25-03-nastaveny-projekt.3mf
models/auticko-silovy-prevod-25/kalibrace/stl/otvory-4-svisle.stl
models/auticko-silovy-prevod-25/rozlozeni/auticko-25-podlozka-03.3mf
models/auticko-silovy-prevod-25/rozlozeni/dotisk-prvni-varky-2026-09-20/dotisk-25-podlozka-02.3mf
models/auticko-s-prevodovkou/stl/kolo-zadni-72z.stl
models/auticko-s-prevodovkou/stl/kolo-zadni-prave.stl
models/auticko-s-prevodovkou/stl/mezikolo-54_18z.stl
models/auticko-s-prevodovkou/stl/osa-hlavni-101_3.stl
models/auticko-s-prevodovkou/stl/osa-mezi-65_2.stl
models/auticko-s-prevodovkou/stl/pastorek-18z-otvor-2_2.stl
models/auticko-s-prevodovkou/stl/plosina-170x60.stl
models/auticko-s-prevodovkou/stl/ram.stl
models/auticko-s-prevodovkou/stl/rozperka-17_6.stl
models/auticko-s-prevodovkou/stl/rozperka-8_6.stl
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

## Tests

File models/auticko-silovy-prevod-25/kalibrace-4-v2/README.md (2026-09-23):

# Ø4 kalibrace V2: větší otvory ve dvou orientacích

**Nový doplňkový vzorek: dva malé bloky, otvory 4,4 / 4,6 / 4,8 mm, skutečná hloubka každého otvoru 8 mm.** Použij znovu původní plně kruhový čep Ø4 × 24 mm. Nový čep se netiskne a jeho průměr se nesnižuje.

**[Připravená podložka 3MF — oba nové bloky](kalibrace-4-v2-podlozka-01.3mf)** obsahuje přesně dva samostatné objekty. V prázdném projektu Anycubic Slicer Next s Kobra X 0,4 mm zvol při nabídce **Import geometry only**, zachovej 100 % měřítko a uložené orientace. Arrange ani Auto orient nejsou potřeba. Soubor obsahuje pouze geometrii, nenastavuje vrstvy, filament, podpory ani další tiskové hodnoty a neobsahuje G-code.

Alternativně [ZIP dvou STL](kalibrace-4-v2.zip), každý soubor jednou. Nemíchat jeho kopie s již načtenou 3MF. Tato složka je **V2**, původní kalibrační sada zůstává beze změny.

| Označení přímo na dílu | Jak jsou otvory při tisku | Rozměry bloku včetně popisků |
|---|---|---|
| **Z V2** | Svisle skrz horní plochu; osa otvoru Z | 47 × 16,6 × 8,6 mm |
| **Y V2** | Vodorovně mezi předním a zadním čelem; osa otvoru Y | 47 × 8 × 10,8 mm |

Každý otvor má nad svým sloupcem vlastní vystouplé číslo **4.4, 4.6 nebo 4.8**. Popisky jsou skutečná tisknutelná geometrie, vysoká 5 mm, s tahy 0,65 mm a vystoupením 0,6 mm. Vodorovný blok má otvory na čele pod popisky. Rozměry jsou nominální CAD, nikoli změřené výtisky.

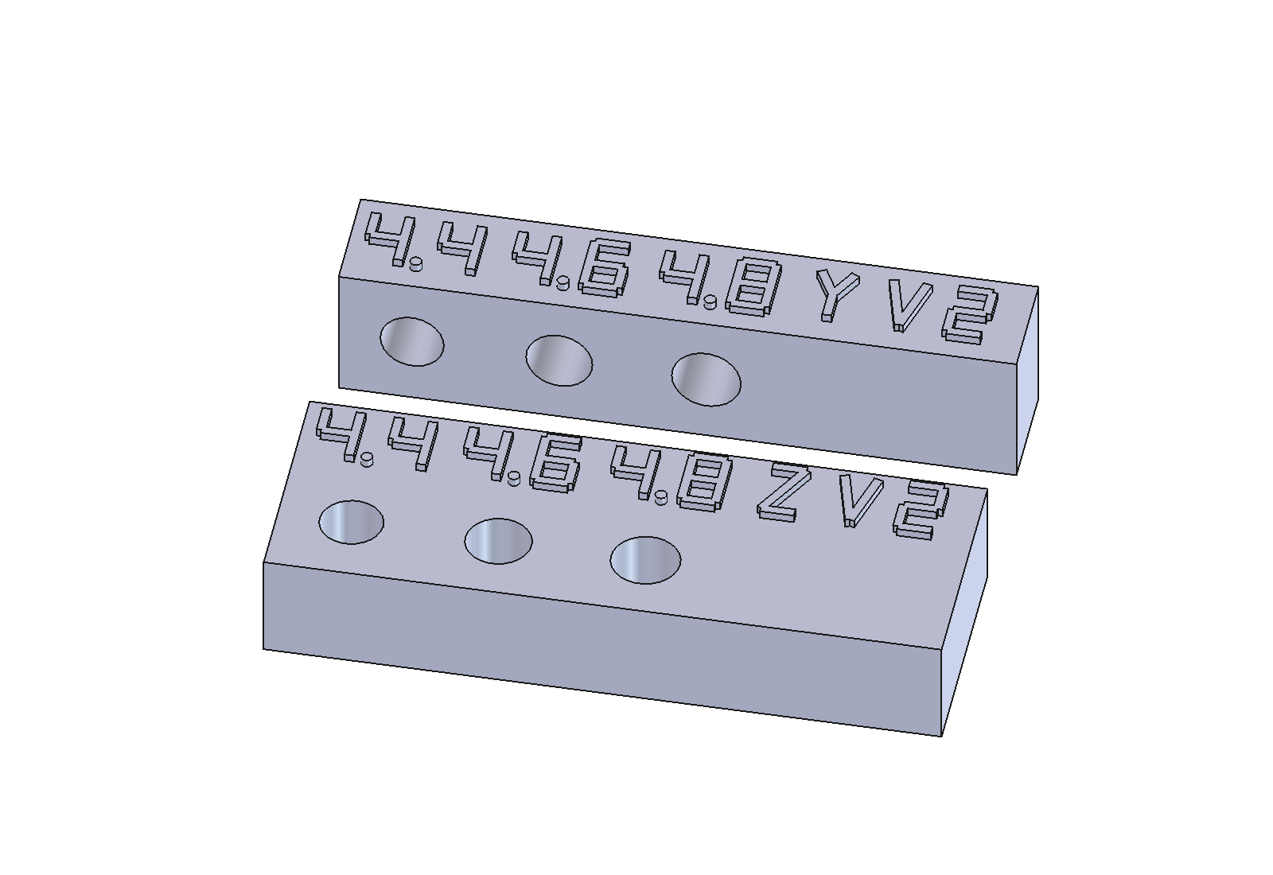
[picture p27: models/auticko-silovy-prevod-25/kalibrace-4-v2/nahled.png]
Skutečný CAD náhled nových dvou vzorků


## Proč vznikl nový vzorek

Jiří hlásí, že největší předchozí otvory 8,6 a 12,6 mm mu subjektivně vyhovují, zatímco původní Ø4 čep se volně neotáčí ani v největším otvoru 4,3 mm. Nejde o změřené průměry ani potvrzení, že každý Ø4 spoj má být volně otočný. **Nové otvory 4,4–4,8 mm zatím fyzicky vyzkoušené nejsou.**

Svislý a vodorovný otvor mohou vyjít při stejném nominálním průměru odlišně. Proto jsou zde obě orientace a zachovaná funkční hloubka 8 mm. Omezili jsme sadu na dva bloky; osm původních vzorků ani další čep není potřeba tisknout znovu. Doba tisku nebyla vypočítána slicerem.

## Jak zkoušet

1. Použij stejný původní Ø4 čep. Odstraň jen volné otřepy a zbytky podpor; nesnižuj celý jeho pracovní průměr broušením, aby prošel. Pokud můžeš měřit, zapiš skutečný průměr v několika směrech. Čep může být po tisku větší či oválný; označení Ø4 je nominální hodnota.
2. Každou řadu zkoušej samostatně, od **4,4 přes 4,6 po 4,8**. Čep musí projít celými 8 mm bez násilí. Zapiš zvlášť výsledek Z a Y, odpor při zasouvání, případné otáčení a boční vůli.
3. **Příčný klínek a montážní zajišťovací čep potřebují především správně zasunout. Volné otáčení není automatickým kritériem pro klínek.** Pro skutečně otočný kloub je navíc nutný lehký chod po celé otáčce. Největší otvor se nemá automaticky převzít do všech spojů; příliš velká vůle může zhoršit vedení a zajištění.
4. Pokud nevyhoví ani 4,8 mm, neaplikuj další zvětšení naslepo. Zaznamenej, zda jde o vstupní hranu, těsný celý otvor, deformaci čepu nebo stopy podpor. Podle konkrétního výsledku se upraví odpovídající spoj hlavního modelu.

Krátký vzorek ověřuje **8 mm vedení**. Nepotvrzuje chod delšího skutečného otvoru, souosost dvou podpor, pevnost klínku ani chování celého mechanismu pod zatížením. Výsledek jedné tiskové orientace nepřenášej automaticky na druhou.

## Tiskové podmínky a meze kontroly

Použij odpovídající skutečný materiál, vrstvy, kompenzaci otvorů a způsob očištění jako u porovnávaných dílů. Uživatel hlásil běžnou vrstvu 0,08 mm a horní vzor Monotonic line; tato 3MF je neaplikuje. První vrstva má vlastní nastavení. Neměň měřítko celé geometrie kvůli fitu otvorů.

U bloku **Y V2** prohlédni ve vrstveném náhledu kruhové stropy vodorovných otvorů: propad nebo stopy podpor mohou ovlivnit průchodnost. Podpory a skutečné dráhy zde nebyly naslicované ani ověřené. Pokud použiješ podpory nebo opracování otvorů, zaznamenej postup a porovnávej s odpovídajícím skutečným dílem. Nový ležatý čep se v této sadě nevyskytuje.

Podložka má 260 × 260 mm. Mezi konzervativními obálkami bloků je **11,05 mm**; rezerva počítá s brimem 5 mm + mezerou 0,1 mm kolem každého dílu. Pro jiné podpory, brim nebo skirt zkontroluj skutečný dosah. Soubor je určen pro tisk po vrstvách.

## Co bylo ověřeno a jak model upravit

- [CAD kontrola](kontrola-kalibrace.json): dva platné jednodílné solidy, šest průchozích otvorů, kontrola osy a okolní stěny v hloubkách 0,05 / 4 / 7,95 mm, přepočet hloubky 8 → 9 → 8 mm, uložení a opětovné otevření FCStd.
- [Přímá kontrola průměrů finálního FCStd](overeni-prumeru.json): 432 bodových zkoušek skutečných vyříznutých otvorů, vždy 0,01 mm uvnitř a vně jmenovitého poloměru, ve 12 směrech a třech hloubkách. Ověřuje CAD průměry, nikoli vytištěné tolerance.
- [STL a ZIP](overeni-exportu.json): rozměry, uzavřenost, orientace, jedna propojená síť na blok, Z0, soulad zdroje a exportů.
- [3MF](overeni-3mf.json) a [počty](overeni-kusovniku.json): přesně dva objekty, původní trojúhelníky a jednotky mm; pouze posuny XY a rotace kolem Z, bez změny měřítka či spodní plochy.
- [Import/export Next](overeni-importu.json): místní CLI v izolované cache zachovalo obě jména a všech 7 108 trojúhelníků; největší číselná odchylka vrcholu je 0,000007634 mm. Neběžel slicing, nevznikl G-code a tiskárna nebyla ovládána. Reexport z CLI není dodávaným souborem, protože obsahuje přidané defaulty.

[Editovatelný FCStd](kalibrace-4-v2.FCStd) obsahuje standardní FreeCAD Part objekty, booleany, tabulku Parameters a výrazy. [Zdrojové makro](kalibrace-4-v2.FCMacro) zapisuje jen tuto složku. Hloubka otvorů je parametrická; **při změně průměrů uprav hodnoty v makru a regeneruj i číselné popisky**, které jsou tvořené nativními tahy bez závislosti na fontu. Samotné přepsání průměru v tabulce neaktualizuje tvar číslic. Po změně znovu vytvoř STL, 3MF, náhledy a kontroly.

[Detail popisků](popisky.png) a [náhledové makro](nahled.FCMacro) zachycují skutečnou CAD geometrii. Náhled není důkazem vytištěné čitelnosti nebo fyzického fitu.

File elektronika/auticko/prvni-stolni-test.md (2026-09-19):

# První stolní zkouška motoru — 19. 9. 2026

**Výsledek podle uživatele: tlačítko v telefonu roztočilo skutečný motor přibližně na jednu sekundu. Po vyjmutí jednoho článku motor už neběžel.** Tím je poprvé potvrzený celý řetězec telefon → Wi-Fi → Arduino UNO R4 WiFi → ST L293D → motor. Jde o krátkou stolní zkoušku; sestavené autíčko, převod pod zátěží ani trvalý provoz ověřené nejsou.

Záznam shrnuje hlasové sestavování a hlášené výsledky. Zapojení bylo kontrolováno jen částečně z fotografií, nikoli proměřeno. Přibližná sekunda je pozorování uživatele; přesné časování, napětí, proud a teplota nebyly fyzicky měřeny. Původní uložení tohoto záznamu neměnilo firmware ani geometrii. **Následnou diagnostiku a upload opravy webu sleduje [samostatný záznam](diagnostika-webu.md); zdejší motorový test patří k dřívější verzi programu.**

## Sestavený obvod a napájení

- **Arduino UNO R4 WiFi:** při stolní zkoušce napájené přes USB-C z powerbanky. Její druhý USB výstup byl zvažován pro motor, ale nakonec se nepoužil; chyběl adaptér pro vyvedení napájecích vodičů.
- **Budič:** uživatelem potvrzený ST L293D DIP16, přes středovou mezeru nepájivého pole. [Úplná tabulka zapojení](zapojeni-l293d.md) odpovídá řídicím pinům [programu](../../models/jednoduche-auticko/firmware/prvni-motor/prvni-motor.ino).
- **Řízení:** Arduino D5 → pin 1, D7 → pin 2, D8 → pin 7. Žlutý vodič **D8 → pin 7** uživatel výslovně zkontroloval na obou koncích. Barva vodiče sama funkci neurčuje.
- **Motor:** dva vodiče na výstupy 3 a 6. Tělo Ø 22,5 × 26 mm a vyčnívající hřídel 6 mm jsou dřívější ruční údaje. Motor nemá označení a není z LaskaKit sady. Rozsah 1–6 V je pouze uživatelem zadaný předpoklad, proud včetně rozběhu není známý. Uživatel před sestavením potvrdil také přímý rozběh při přidržení bateriových vodičů na kontaktech; použitý zdroj tehdy nebyl přesně určen.
- **Zem:** piny 4, 5, 12, 13, Arduino GND a černý vodič držáku na společném nepřerušeném úseku modré lišty. Nepoužité řízení 9, 10, 15 má podle postupu patřit na GND; výstupy 11 a 14 zůstávají volné. Celý obvod nebyl vizuálně potvrzen pin po pinu.
- **Logika:** pin 16 na červenou lištu připojenou k 5 V Arduina.
- **Motorové napájení:** červený vodič sériového držáku čtyř AA přímo do propojené pětice pinu 8. Kladná větev držáku se nespojuje s červenou 5V lištou Arduina.

V konkrétní poloze při skládání byl výřez čipu **vlevo**, směrem dovnitř pole. Při pohledu shora je spodní řada zleva **1–8** a horní zleva **16–9**. Volný otvor u nožičky musí patřit do stejné propojené pětice; u napájecí lišty rozhoduje stejný nepřerušený úsek. Polohu v otvoru nelze spolehlivě odvozovat jen z horního konce vysokého plastového konektoru na šikmé fotografii.

### Skutečné články při zkoušce

V držáku byly **smíšené nabíjecí Ni-MH a běžné články**. Na šedém článku bylo ve fotografii čitelné Ni-MH a uživatel později potvrdil údaj **1,2 V**; vedle byl článek VARTA LONGLIFE MAX POWER. Původní tvrzení o čtyřech běžných 1,5V článcích bylo tímto opravené. Úplné složení po vložení posledního článku, stav nabití ani napětí celého držáku nebyly ověřeny. Skutečný zdroj proto **neoznačovat jako změřených 6 V**.

Uživatel na krátkém pokusu s dostupnými články trval; byl upozorněn, že tato směs není řešení pro běžný provoz. Záznam úspěšného rozběhu není doporučením tento způsob napájení opakovat. Pro další provoz použít sadu odpovídajících článků stejného typu a obdobného stavu, ověřit napětí a proudové možnosti vůči budiči i motoru. [Pokyny výrobce baterií k nemíchání typů a starých/nových článků](https://energizer.com/about-batteries/battery-care/).

**Vyjmutí jedné baterie z tohoto sériového držáku přeruší celý obvod.** Není to zkouška motoru na napětí zbývajících tří článků. Arduino může dál běžet z oddělené USB powerbanky a reagovat LED, zatímco motor nemá uzavřený napájecí obvod.

### Odpor, kondenzátory a dočasné kontakty

- Pro odpor **10 kΩ mezi pinem 1 a GND** byl na fotografii `20260919_030519.jpg` vybraný prostřední pás v průhledném sáčku: pět proužků **hnědá–černá–černá–červená–hnědá**, tedy 10 kΩ ±1 %. Uživatel potvrdil zapojení. D5 zůstává připojený přímo k pinu 1; odpor není v sérii se signálem. Orientace odporu nerozhoduje.
- Návrh obsahuje dva keramické **100 nF** u napájení čipu, 16–GND a 8–GND. **Při této zkoušce nebyl osazen žádný kondenzátor**, protože je uživatel neměl a chtěl pokračovat. Jeden úspěšný pulz neověřuje odolnost proti rušení, poklesům napětí či resetům; pro stabilní sestavu odrušení doplnit.
- Součástka s označením **SW-520D** je kuličkový náklonový spínač, ne kondenzátor. Do místa kondenzátoru nepatří.
- Při této první zkoušce uživatel neměl páječku, cín ani malé krokosvorky. Později potvrdil nákup páječky, pájky a dalších pomůcek v Hornbachu, viz [inventář](../vybaveni.md); zapájení kontaktů dosud nepotvrdil. Odizolované konce obou vodičů protáhl otvory motorových kontaktů a zahnul kolem plíšků. Jde o **dočasný mechanický kontakt bez pájení**, nikoli hotový spoj pro jízdu. Holé části mají zůstat oddělené od sebe a kovového pláště; před mechanickou montáží je potřeba spolehlivé připojení a odlehčení tahu.

## Průběh zkoušky

| Krok | Hlášený výsledek a co dokládá |
|---|---|
| Sestavování bez USB a s jednou AA mimo držák | Vodiče byly připojované bez napájení. Jednotlivé kroky potvrzoval uživatel. |
| Připojení pouze USB powerbanky, AA stále mimo držák | Rozsvítila se kontrolka napájení Arduina; motorová větev zůstala přerušená. |
| Telefon v síti `Auticko-test`, stránka se nejprve nenačetla | Po otevření výslovného odkazu **[http://192.168.4.1/](http://192.168.4.1/)** uživatel potvrdil funkční stránku. Záměna HTTP/HTTPS byla možnost, nikoli zachycená a prokázaná příčina. |
| Tlačítko „Test motoru na 1 sekundu“ bez motorového napájení | LED Arduina podle uživatele svítila asi sekundu; to samo ještě nebyl běh motoru. |
| Vložení poslední AA, tlačítko zatím nestisknuté | Motor podle uživatele zůstal stát. |
| Jeden vědomý stisk tlačítka | Uživatel oznámil, že se motor na sekundu rozběhl. První fyzický motorový test přes L293D vyšel. |
| Následné vyjmutí jedné AA a další zkouška | Uživatel potvrdil, že motor už nefunguje; držák má přerušený sériový obvod. |

Test byl vedený jako krátký stolní pokus s volným motorem, bez ověření pohonu kol. Program dává jeden pulz s PWM **128/255**, potom výstup vypne a motor může dobíhat; nejde o aktivní brzdu. Uvolnění tlačítka délku pulzu nezkracuje. Přesný směr budoucí jízdy z tohoto testu neplyne, závisí na zapojení kontaktů a orientaci motoru v sestavě.

**Stav na konci této první zkoušky:** jedna baterie vyjmutá, motorový zdroj přerušený, Arduino na USB powerbance. Později uživatel napájení přepojoval a motor zkoušel znovu; aktuální stav držáku nelze odvodit z tohoto historického zápisu. Navazující diagnostika probíhala přes USB počítače.

## Fotografie a opravy během sestavování

Uživatel poskytl archiv `Photos-1-001.zip` se snímky `20260919_033207.jpg`, `20260919_033204.jpg` a `20260919_033158.jpg`. Místní originál je `/home/novakj/Downloads/Photos-1-001.zip`; fotografie odporů je `/home/novakj/Downloads/20260919_030519.jpg`. Originály zůstávají mimo repozitář, odkazy na tato jména jsou evidence původu, nikoli přenositelná fotopříloha. Rozbalená pracovní kopie v cache není kanonický projektový záznam.

Na dodaných snímcích byly vidět odpojené USB, jedna chybějící baterie a čip přes mezeru pole. Některé nožičky, orientační značku a řady otvorů zakrývaly konektory. **Celé zapojení tedy nebylo z fotografií potvrzeno.** Uživatel požádal kontrolovat až na konci a potom postupovat podle jeho kontroly zapojení.

- Předchozí hlasový pokyn **pin 8 → GND byl chybný**. Byl odvolán a uživatel potvrdil odpojení tohoto vodiče; konečné určení pinu 8 je plus motorového zdroje.
- Podezření z šikmé fotografie, že žlutý vodič končí na D7, bylo odvoláno. Uživatel přímo potvrdil **D8 na Arduinu → pin 7 čipu**. Není doloženo, že zde skutečně byla chyba nebo proběhlo přepojení.
- První zjištěný modul **ULN2003AN** není reverzační H-můstek, ale za odpovídajících elektrických podmínek umí spínat DC motor jedním směrem. Tvrzení, že je výhradně pro krokové motory, bylo opraveno. Pro tuto sestavu se nakonec použil potvrzený **ST L293D**.

## Mechanika a další pokračování

Uživatel už potvrdil, že vytištěný **pastorek s nominálním CAD otvorem 2,2 mm dobře pasuje na motor**. Zkouška vzorku ani nasazení nejsou měřením skutečného průměru hřídelky. Přenos momentu pastorkem a záběr soukolí pod zátěží zůstávají neověřené.

Tisk zbývajících **13 kusů z devíti typů STL** uživatel oznámil jako zadaný; slicer ukázal **3 h 15 min**. Dokončení, skutečný čas, profil a cívka ještě potvrzené nejsou. Počty a montážní pořadí jsou v [README modelu](../../models/jednoduche-auticko/README.md), tisková historie v [deníku](../../docs/denik-tisku.md).

Pro další pokračování zbývá:

1. Potvrdit dokončení ostatních dílů a jejich mechanický fit, volné osy, zajištění kol, uchycení motoru a soukolí.
2. Dokončit spolehlivé motorové spoje a odrušení, vyřešit odpovídající napájení bez směsi článků a ověřit skutečné elektrické parametry. První pulz nepotvrzuje rezervu proudu ani teplotní chování L293D.
3. Teprve potom ověřit pohon celé sestavy a jízdu. Tehdejší firmware i pozdější recovery verze prováděly sekundový test. Následně byl nahrán chod při držení tlačítka `hold-to-run-v1`; uživatel jej nejprve hodnotil příznivě, poté ale hlásil [potíže a neúspěšný rozjezd i s koly ve vzduchu](potize-po-montazi.md). Tento historický sekundový rozběh neověřuje nové řízení ani příčinu nynějších potíží. Aktuální použití a časové limity jsou v [návodu k firmwaru](../../models/jednoduche-auticko/firmware/prvni-motor/README.md). Reverzace součástí nového režimu není.

Při dalším vedení montáže chce uživatel **jeden konkrétní krok najednou**. Hotové zapojení nepřestavovat jen podle barev vodičů; vycházet z pinů, uživatelského potvrzení a případného měření.

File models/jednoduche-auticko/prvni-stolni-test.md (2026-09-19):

# První stolní zkouška motoru — 19. 9. 2026

Dokumentace se přesunula do samostatné sekce elektroniky:

**[Otevřít aktuální dokument](../../elektronika/auticko/prvni-stolni-test.md)**

Tato cesta zůstává pouze kvůli starším odkazům. Nové poznatky zapisovat do cílového dokumentu.

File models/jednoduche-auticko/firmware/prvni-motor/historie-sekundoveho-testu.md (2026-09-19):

# Historická dokumentace sekundového testu

Archiv stavu před změnou na ovládání při držení dne 19. 9. 2026. Slova „aktuální“ a časové údaje níže se vztahují k této starší etapě, nikoli k nynější verzi. Platný návod je v [README](README.md); podrobná historie je také v [elektronice autíčka](../../../../elektronika/auticko/README.md).

# První sekundový test motoru

Jednoduchý zkušební firmware pro **Arduino UNO R4 WiFi** a **ST L293D DIP16**. **Uživatel 19. 9. 2026 potvrdil skutečný přibližně sekundový rozběh motoru po stisku tlačítka v telefonu.** Po vyjmutí jednoho článku z držáku už motor neběžel. [Záznam stolního testu](../../prvni-stolni-test.md) uvádí přesný rozsah potvrzení a provizorní podmínky: smíšené články, bez kondenzátorů a bez pájených motorových spojů. Napětí, proud ani fyzické časování se neměřily; jízda celého autíčka nebyla zkoušena.

**Aktuálně je nahraná oprava zotavení webu po přechodné chybě Wi-Fi.** Diagnostika na desce prokázala, že původní program po výsledku 255 trvale zakázal obsluhu. Nová verze stav znovu kontroluje, po zotavení obsluhu obnoví a odmítá staré či opožděné motorové požadavky. Pulz zůstal nezměněný. Prošlo původních 53 + 53 regresí, testy tokenů, osm scénářů zotavení a testy diagnostiky; překlad má **74 796 B flash / 8 868 B RAM**, upload **74 804 B / 19 stran** byl úspěšný. Zkouška telefonu a fyzického motoru s touto novou verzí zatím není potvrzená. [Postup, evidence a omezení opravy](../../diagnostika-webu.md).

Motor **1–6 V** je uživatelem zadaný pracovní předpoklad, nikoli ověřený údaj výrobce. Konkrétní zapojení je v [návodu pro L293D](../../zapojeni-l293d.md), širší kontext a historie součástek v [elektronice modelu](../../elektronika.md). Níže uvedené starší uploady a test pouze LED jsou historické kroky před skutečným rozběhem.

## Co udělá

Po startu drží motor vypnutý a vytvoří vlastní Wi-Fi síť **Auticko-test**, heslo **auticko123**. Jde o veřejné demonstrační heslo, nikoli údaj k domácí Wi-Fi. Příprava přístupového bodu trvá přibližně 10 sekund. Po připojení k této síti se stránka otevírá na **[http://192.168.4.1/](http://192.168.4.1/)**, port 80, bez HTTPS. Telefon může správně hlásit síť bez internetu; web obsluhuje samo Arduino.

Stránka má jediné tlačítko **Test motoru na 1 sekundu**. Platný POST vyvolá jeden pulz: IN1 HIGH, IN2 LOW a osmibitové PWM EN **128/255**. Po `delay(1000)` se EN nastaví na nulu a oba směrové vstupy na LOW. Motor může volně dobíhat; nejde o aktivní brzdu. Skutečný směr závisí na zapojení vývodů motoru.

**Puštění tlačítka, zavření stránky ani odpojení prohlížeče pulz okamžitě nezkrátí.** Jde o konečný sekundový test, nikoli finální řízení autíčka. Během zapnutého pulzu se nevolá Wi-Fi ani Serial; odpověď prohlížeči se posílá až po vypnutí výstupu. Časování je softwarové, nikoli nezávislá hardwarová pojistka.

Během čekání je tlačítko vypnuté. Potvrzená odpověď dovolí další vědomé kliknutí. Při chybě nebo šestisekundovém síťovém timeoutu stránka ohlásí nejistý výsledek, tlačítko ponechá vypnuté a nic automaticky neopakuje. Po chybě nejprve ověřit skutečný stav, teprve potom stránku znovu otevřít. Obnovení stránky samo motor nespouští.

## Řídicí piny

| Arduino | L293D DIP16 | Význam |
|---|---|---|
| D5, PWM | 1 — EN1,2 | Povolení výstupů první dvojice |
| D7 | 2 — IN1 | První směrový vstup |
| D8 | 7 — IN2 | Druhý směrový vstup |

Program navíc používá pouze `LED_BUILTIN` jako indikaci pulzu. Tabulka uvádí řídicí propojení, nikoli celé elektrické zapojení. Chybný stav Wi-Fi vypne výstupy a zneplatní oprávnění k testu z otevřené stránky. Během výpadku se kontrola opakuje s odstupem nejméně jedné sekundy; po návratu platného stavu se web obnoví. Před dalším testem je nutné znovu načíst stránku. Obnova sítě sama motor nespustí; knihovní čekání na modem může trvat déle než uvedený odstup.

## Jednoduchý HTTP protokol

- `GET / HTTP/1.1` vrátí stránku a nikdy nespustí motor. Favicon, jiné cesty, jiné metody a neúplné požadavky motor nespouštějí.
- Motor spouští pouze přesné `POST /test HTTP/1.1` po kompletním zakončení hlaviček `CRLF CRLF`, s `Host: 192.168.4.1` (případně `:80`), právě jedním `Content-Length: 0`, `X-Motor-Test: 1` a `X-Motor-Token` s aktuálním jednorázovým tokenem ze stránky.
- Každé načtení stránky vytvoří nový token a zneplatní předchozí. Platný test jej spotřebuje ještě před dalším dotazem na Wi-Fi a pulzem. Odpověď po STOP má tvar `TEST_OK:<nový token>` a dovolí další vědomý stisk; opakování stejného POST nebo stará stránka po výpadku test nespustí. Token není náhradou přihlášení. Generování používá výchozí hardwarový generátor core 1.6.0; při jeho chybě se další test nepovolí.
- JavaScript posílá prázdné tělo; `Content-Length: 0` doplňuje prohlížeč. Skript nenastavuje tuto pro JavaScript zakázanou hlavičku ručně.
- Vlastní hlavička a nepovolené CORS brání běžnému nechtěnému vyvolání cizí webovou stránkou. Pokud je přítomný `Origin`, musí odpovídat místní stránce. Nejde o samostatné přihlašování; zařízení připojené k této testovací síti může správný požadavek vytvořit.
- Příjem má aplikační limit **3 sekundy**, nejvýše **8192 bajtů** celého požadavku a **1024 znaků** na řádek. Dřívější limit 128 znaků odmítal běžné dlouhé mobilní hlavičky. Statické pole řádku používá 1025 B RAM mimo zásobník; celý požadavek se v paměti nehromadí. Server zpracovává vždy pouze jedno spojení. Kontrolují se CRLF, názvy hlaviček, nulové tělo, duplicity kritických hlaviček; `Transfer-Encoding` a `Expect` se odmítají. Podkladové Wi-Fi volání není tvrdý real-time časovač; během příjmu je motor vypnutý.
- Těsně před pulzem se znovu kontroluje Wi-Fi a stáří obsluhy požadavku. Pokud včetně čekání na modem dosáhlo 3 s, test se odmítne a token zůstane spotřebovaný. Tím se brání dodatečnému rozběhu po dlouhém AT čekání; nejde o měření stáří paketu před převzetím z modemu.
- Po jedné odpovědi se spojení uzavře. Pro další pulz musí přijít nový úplný platný POST s novým tokenem. Požadavek neobsahuje volitelnou délku, směr ani výkon.

## Zdroj a ověření

[prvni-motor.ino](prvni-motor.ino) používá přibalenou knihovnu `WiFiS3`. Vytvoření AP vychází z [oficiálního příkladu Arduino AP_SimpleWebServer](https://github.com/arduino/ArduinoCore-renesas/blob/main/libraries/WiFiS3/examples/AP_SimpleWebServer/AP_SimpleWebServer.ino); IP je výslovně nastavená přes `WiFi.config(IPAddress(192,168,4,1))`. Odpovídající API popisuje [WiFi.h v oficiálním Arduino core](https://github.com/arduino/ArduinoCore-renesas/blob/main/libraries/WiFiS3/src/WiFi.h).

Hostová kontrola skutečného zdrojového kódu s náhradami Arduino/Wi-Fi API prošla pro **53 případů parseru a stejných 53 případů celého `loop()`**: platné požadavky, neúplné/chybné hlavičky, jiné metody a cesty, duplicity, cizí Host/Origin, nenulové tělo, CRLF, délku řádku i celkový limit a pomalý příjem. Parsování nezapisovalo motorové piny. Simulovaný pulz trval přesně 1000 ms, během něj nebylo síťové I/O a skončil vypnutým EN i směrovými vstupy. Start bez Wi-Fi modulu ponechal výstupy vypnuté. Testy běžely pouze na počítači a neověřují chování fyzického motoru.

Kompilace opravy zotavení byla ověřena **Arduino CLI 1.5.1**, deska `arduino:renesas_uno:unor4wifi`, core **1.6.0**: flash **74 796 / 262 144 B**, RAM **8 868 / 32 768 B**. Vložený JavaScript prošel `node --check`. Testy a zdrojový review pokrývají také spotřebu a výměnu tokenů, opakovaný POST, chybové stavy s následným zotavením a opožděný dotaz na modem. Přesné kontrolní součty a oddělenou historii uploadů uchovává [ověření programu](overeni-programu.json).

Arduino IDE **2.3.10** má nainstalovanou podporu Renesas **1.6.0**. Po výměně kabelu se UNO R4 WiFi skutečně detekovalo na **`/dev/ttyACM0`** a následně byla opravena oprávnění portu. Jeho existence i přístup pro čtení/zápis byly znovu ověřené. Původní stav „USB nedetekováno“ už neplatí.

Uživatel potvrdil **úspěšný upload 51 824 B**. Lokální kontrola posledního `sketch_sep19a.ino` potvrdila jen prázdné `setup()` a `loop()` s výchozími komentáři. Jde o úspěšné nahrání prázdného sketche; **tehdy ještě nešlo o motorový program**. Nebyl proveden read-back firmware z desky; zdrojem informace je uživatelské hlášení a kontrola lokálního sketche.

Motorový sketch byl otevřený příkazem níže v novém okně stávajícího IDE, bez uploadu:

```bash
/home/novakj/Downloads/arduino-ide_2.3.10_Linux_64bit.AppImage \
  /home/novakj/3d-print/models/jednoduche-auticko/firmware/prvni-motor/prvni-motor.ino
```

Otevření bylo ověřené názvem nového okna **`prvni-motor | Arduino IDE 2.3.10`**; současně zůstalo otevřené původní **`sketch_sep19a | Arduino IDE 2.3.10`** ve stejném procesu IDE. Oba `.ino` soubory mají shodné SHA256 před a po otevření. Příkaz pouze otevírá zdroj, nenahrává jej. Kontrola kódu, otevřené okno ani úspěšná kompilace nepotvrzují elektrickou vhodnost zapojení či rozběh motoru.

**Následný upload motorového programu:** uživatel dodal dokončený log překladu **67 820 B flash / 7 580 B RAM** a zápisu **67 828 B, 17 stran, 100 %**, bez chyby. Nejnovější lokální `build.options.json` ukazuje zdejší `prvni-motor` a správné FQBN UNO R4 WiFi; odpovídající `.bin` má 67 828 B a zdroj má nezměněný kontrolní součet. Tím je doložen úspěšný uživatelský upload motorového programu, nikoli zatím funkce Wi-Fi nebo motoru. Starší samostatný překlad CLI výše měl 67 804 B; údaje obou běhů nejsou zaměňované. Firmware z desky nebyl čten zpět.

### Oprava mobilního prohlížeče

Uživatel po úspěšném uploadu viděl Wi-Fi `Auticko-test`, připojil telefon a při otevření místní HTTP adresy obdržel text „Neplatny nebo neuplny pozadavek.“. To dokládá spojení a HTTP odpověď, nikoli funkční ovládací stránku. Původní parser omezoval každý řádek na 128 znaků a celý požadavek na 1024 B. Aktuální změna zvyšuje tyto limity na 1024 znaků / 8192 B a aplikační čas příjmu na 3 s; striktní validace spouštěcího POST, Host, Origin a nulového těla i sekundový motorový pulz zůstávají zachované. Konkrétní síťový požadavek uživatelova telefonu nebyl zachycen.

**Ověření opravy a nahrání:** reprezentativní mobilní GET/POST prošly, GET a neplatný POST neaktivují motor; zkoušky obou limitů a třísekundového deadline prošly. [Regresní testy](tests/README.md) běží proti skutečnému zdroji. Buffer řádku je statický, protože konfigurace UNO R4 rezervuje pro hlavní zásobník pouze 0x400 B. Finální zdroj byl přeložen (67 804 B flash, 8 604 B statická RAM) a agent jej úspěšně nahrál na potvrzenou UNO R4 WiFi: 67 812 B, 17 stran, 100 %, návratový kód 0. Motorový test agent nevyvolal. Uživatel následně nejprve potvrdil úspěšné načtení opravené stránky a reakci LED bez externích součástek; tento první test nebyl ověřením motoru ani měřením délky pulzu.

### Následné fyzické ověření

Po sestavení L293D a motoru uživatel znovu potvrdil stránku a LED s odpojeným motorovým napájením. Při dočasných potížích s načtením pomohl výslovný HTTP odkaz; konkrétní požadavek telefonu nebyl zachycen, takže příčina nebyla prokázaná. Následně doplnil poslední baterii do držáku: motor zůstal stát a po jednom stisku tlačítka se přibližně na sekundu rozběhl. Po vyjmutí článku už motor neběžel. To je uživatelské potvrzení skutečného stolního běhu, nikoli měření elektrických rezerv či test celého podvozku. [Úplné podmínky a poslední stav](../../prvni-stolni-test.md).

Následně byla na desce zachycena konkrétní závada: po chybovém výsledku Wi-Fi 255 zůstala původní verze trvale v `ready=false`. Aktuální oprava byla přeložena a nahrána; její podrobnosti jsou v [diagnostice webu](../../diagnostika-webu.md). Při dalším problému nejprve ověřit síť `Auticko-test` a výslovné HTTP. Obnova řeší přechodný chybový stav, nikoli prokazatelně všechny příčiny výpadku ESP nebo listeneru. Důvod samotné hodnoty 255 a dlouhodobá stabilita zatím ověřené nejsou.

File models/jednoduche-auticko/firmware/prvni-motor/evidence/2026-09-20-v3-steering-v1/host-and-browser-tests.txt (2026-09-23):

Sketch: /home/novakj/3d-print/models/jednoduche-auticko/firmware/prvni-motor/prvni-motor.ino
SHA256: 9f7477c851898e97e7c9fd50ca632104c9214259b415a3fa9996ca6a48d8760c
PASS 109 parser + 109 complete HTTP loop cases (no request alone starts motor)
PASS arm never moves; fresh challenge starts, heartbeat renews, stop latches, new press works
PASS STOP before delayed ARM or first HOLD prevents later start
PASS duplicate and in-flight heartbeat after STOP cannot restart
PASS expired ARM needs new real press
PASS independent IRQ cuts motor within 505 ms without loop or heartbeat; expired HOLD cannot renew
PASS page refresh stops output and invalidates previous session
PASS fresh delayed heartbeat gets full 500ms lease from receipt, fixing double-RTT expiry
PASS press counter never wraps within a session
PASS watchdog deadline survives millis wraparound
PASS 20 sustained heartbeat cycles each at 200/250/300/400ms intervals stay live
PASS ARM waits OFF up to 3000ms but first challenge remains bounded to 500ms
PASS obsolete STOP/ARM/HOLD and malformed requests cannot stop or renew newer press
PASS lost STOP plus last delayed in-flight HOLD still switches OFF within 1000ms of release
PASS session rotation stops; repeated recovery request returns current session without cutting new run
PASS older session replay rejected; only immediately previous recovery token is idempotent
PASS normal page navigation clears recovery cache and fences old sessions
PASS new real press may acquire fresh session after boot without browser reload; session alone is OFF
PASS session RNG failure is OFF and next explicit recovery request can succeed
PASS blocking status: IRQ cutoff=500 ms
PASS blocking connected: IRQ cutoff=500 ms
PASS blocking available: IRQ cutoff=500 ms
PASS blocking read: IRQ cutoff=500 ms
PASS blocking write: IRQ cutoff=500 ms
PASS blocking stop: IRQ cutoff=500 ms
PASS blocking serial: IRQ cutoff=500 ms
PASS partial or stalled HTTP cannot prolong motor lease
PASS transient WiFi 255/0/77 stops; rate-limited recovery keeps server and rejects queued old session
PASS missing module at startup can recover, never starts motor
PASS server start failure can recover without motion
PASS AP start failure can recover without motion
PASS boot always OFF; old page cannot start before new page load
PASS RNG failure or exhausted token counter cannot authorize motion
PASS PWM or watchdog initialization failures fail closed
PASS challenge RNG failure stops instead of running without next challenge
PASS PWM update failure and failed PWM OFF use GPIO fallback, disallow further motion
PASS startup uses only nominal1500us; servo-only ARM/HOLD/session never powers motor; PWM490/50 retained
PASS single-flight intent updates independently release motor/steering; duplicate and after-STOP intents cannot restore either
PASS shared500ms IRQ expiry stops motor and centers steering; late steering cannot resurrect expired lease
PASS page/session invalidation also centers servo and fences old control packets
PASS WiFi invalidation clears both actuator intentions
PASS servo initialization/update/neutral failure disables both control paths and falls back to LOW, never claims centering
PASS steering IRQ under blocking status
PASS steering IRQ under blocking connected
PASS steering IRQ under blocking available
PASS steering IRQ under blocking read
PASS steering IRQ under blocking write
PASS steering IRQ under blocking stop
PASS steering IRQ under blocking serial
PASS all host checks (34 named protocol/recovery/failure scenarios); no hardware accessed
PASS browser load/click/secondary pointer do not start motor
PASS browser mouse hold chain, release, next real press
PASS browser touch hold chain, release, next real press
PASS browser pointercancel stops and requires new press
PASS browser lostpointercapture stops and requires new press
PASS browser blur stops and requires new press
PASS browser pagehide stops and requires new press
PASS browser offline stops and requires new press
PASS browser visibilitychange stops and requires new press
PASS browser unrelated pointer release does not stop current hold
PASS browser delayed ARM response after release never sends HOLD
PASS browser delayed HOLD after release cannot schedule another heartbeat or show running
PASS browser network failure stops without automatic retry
PASS browser HTTP failure stops without automatic retry
PASS browser bad-challenge failure stops without automatic retry
PASS browser timeout failure stops without automatic retry
PASS browser failed STOP requires new press then recovers session without reload
PASS browser error while still physically held requires release before new session
PASS browser release while recovery response pending cannot arm or run
PASS browser keyboard Space down/up and repeat suppression
PASS browser keyboard Enter down/up and repeat suppression
PASS browser steering alone and release never request motor power
PASS browser steering first, secondary touch drives; releasing drive preserves steering with motor0
PASS browser drive first, secondary touch steers; steering release preserves motor and centers
PASS browser intent change during outstanding HOLD waits for nonce, never parallelizes HOLD
PASS browser center alone sends only STOP; center while driving retains drive but clears turn
PASS browser opposing steering touches request neutral until one releases
PASS browser arrow keys independently control motor and steering
PASS browser combined controls cancel invalidates both and never resumes held input
PASS browser combined controls network invalidates both and never resumes held input
PASS browser combined controls blur invalidates both and never resumes held input
PASS browser combined controls offline invalidates both and never resumes held input
PASS browser combined controls hidden invalidates both and never resumes held input
PASS 33 actual-inline-JavaScript browser scenarios; no hardware or network accessed
PASS Chromium HTTP hold >2s with 200ms roundtrip +20ms browser pause
PASS Chromium HTTP hold >2s with 300ms roundtrip +20ms browser pause
PASS Chromium HTTP hold >2s with 400ms roundtrip +20ms browser pause
PASS Chromium HTTP jittered response chain remains live then touch release stops
PASS Chromium HTTP release while ARM response pending cannot start motor
PASS Chromium HTTP dropped STOP expires without retrigger, new press refreshes session
PASS Chromium HTTP HOLD loss stops; connection recovery alone cannot restart
PASS Chromium HTTP lost session response can retry on next press without token lockout
PASS Chromium HTTP stale duplicate HOLD and earlier STOP do not cut a newer press
PASS Chromium HTTP real multitouch drive first, independent release and safe stop
PASS Chromium HTTP real multitouch left first, independent release and safe stop
PASS Chromium HTTP servo-only keyboard, explicit center, combined arrows and focus loss
PASS Chromium HTTP dropped STOP with both actuators returns motorOFF/neutral without new input
Screenshot: /home/novakj/3d-print/elektronika/auticko/nahled-ovladani-v3.png
PASS Chromium HTTP mobile UI has no overflow and screenshot is actual sketch page
PASS 14 real Chromium HTTP scenarios against actual persistent C++ sketch; hardware remains mocked

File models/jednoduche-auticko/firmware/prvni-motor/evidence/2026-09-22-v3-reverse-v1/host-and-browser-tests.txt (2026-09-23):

Sketch: /home/novakj/.codex/worktrees/e339/3d-print/models/jednoduche-auticko/firmware/prvni-motor/prvni-motor.ino
SHA256: d24a87631fd32a41685baedd7488c425a75ca6f9e300706349c61e09e79fe930
PASS 120 parser + 120 complete HTTP loop cases (no request alone starts motor)
PASS arm never moves; fresh challenge starts, heartbeat renews, stop latches, new press works
PASS STOP before delayed ARM or first HOLD prevents later start
PASS duplicate and in-flight heartbeat after STOP cannot restart
PASS expired ARM needs new real press
PASS independent IRQ cuts motor within 505 ms without loop or heartbeat; expired HOLD cannot renew
PASS page refresh stops output and invalidates previous session
PASS fresh delayed heartbeat gets full 500ms lease from receipt, fixing double-RTT expiry
PASS press counter never wraps within a session
PASS watchdog deadline survives millis wraparound
PASS 20 sustained heartbeat cycles each at 200/250/300/400ms intervals stay live
PASS ARM waits OFF up to 3000ms but first challenge remains bounded to 500ms
PASS obsolete STOP/ARM/HOLD and malformed requests cannot stop or renew newer press
PASS lost STOP plus last delayed in-flight HOLD still switches OFF within 1000ms of release
PASS session rotation stops; repeated recovery request returns current session without cutting new run
PASS older session replay rejected; only immediately previous recovery token is idempotent
PASS normal page navigation clears recovery cache and fences old sessions
PASS new real press may acquire fresh session after boot without browser reload; session alone is OFF
PASS session RNG failure is OFF and next explicit recovery request can succeed
PASS blocking status: IRQ cutoff=500 ms
PASS blocking connected: IRQ cutoff=500 ms
PASS blocking available: IRQ cutoff=500 ms
PASS blocking read: IRQ cutoff=500 ms
PASS blocking write: IRQ cutoff=500 ms
PASS blocking stop: IRQ cutoff=500 ms
PASS blocking serial: IRQ cutoff=500 ms
PASS partial or stalled HTTP cannot prolong motor lease
PASS transient WiFi 255/0/77 stops; rate-limited recovery keeps server and rejects queued old session
PASS missing module at startup can recover, never starts motor
PASS server start failure can recover without motion
PASS AP start failure can recover without motion
PASS boot always OFF; old page cannot start before new page load
PASS RNG failure or exhausted token counter cannot authorize motion
PASS PWM or watchdog initialization failures fail closed
PASS challenge RNG failure stops instead of running without next challenge
PASS PWM update failure and failed PWM OFF use GPIO fallback, disallow further motion
PASS startup uses only trimmed1575us; servo-only ARM/HOLD/session never powers motor; PWM490/50 retained
PASS single-flight intent updates independently release motor/steering; duplicate and after-STOP intents cannot restore either
PASS shared500ms IRQ expiry stops motor and centers steering; late steering cannot resurrect expired lease
PASS page/session invalidation also centers servo and fences old control packets
PASS WiFi invalidation clears both actuator intentions
PASS servo initialization/update/neutral failure disables both control paths and falls back to LOW, never claims centering
PASS steering IRQ under blocking status
PASS steering IRQ under blocking connected
PASS steering IRQ under blocking available
PASS steering IRQ under blocking read
PASS steering IRQ under blocking write
PASS steering IRQ under blocking stop
PASS steering IRQ under blocking serial
PASS both polarities at PWM128 support unchanged left/right/center and independent motor release
PASS reversal first drops EN then both inputs; REARM cancels nonce/press; time/retry cannot restart either polarity
PASS 250ms is measured from continuous actual OFF; neutral updates do not restart pause; exact boundary accepts new press
PASS STOP/ARM/session/page do not bypass opposite-direction OFF interval or revive rejected sequence
PASS invalid signed intents and stale nonce cannot mutate/renew reverse; watchdog expiry latches whole sequence OFF
PASS reversal OFF interval survives uint32 millis wraparound
PASS lost STOP and last delayed reverse HOLD still expire within 1000ms of release
PASS reverse PWM start/OFF failure leaves both bridge inputs LOW and disables future motion
PASS reverse IRQ under blocking status
PASS reverse IRQ under blocking connected
PASS reverse IRQ under blocking available
PASS reverse IRQ under blocking read
PASS reverse IRQ under blocking write
PASS reverse IRQ under blocking stop
PASS reverse IRQ under blocking serial
PASS all host checks (42 named protocol/recovery/failure scenarios); no hardware accessed
PASS browser load/click/secondary pointer do not start motor
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

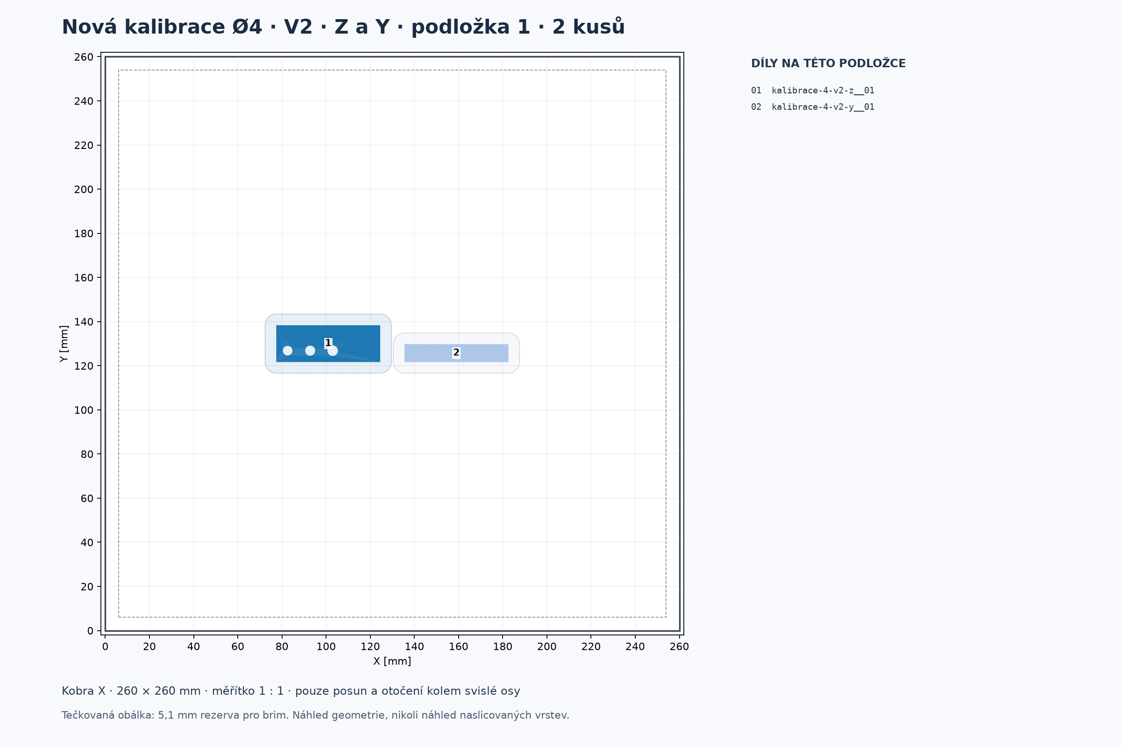
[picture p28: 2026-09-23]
models/auticko-silovy-prevod-25/kalibrace-4-v2/podlozka-01.png

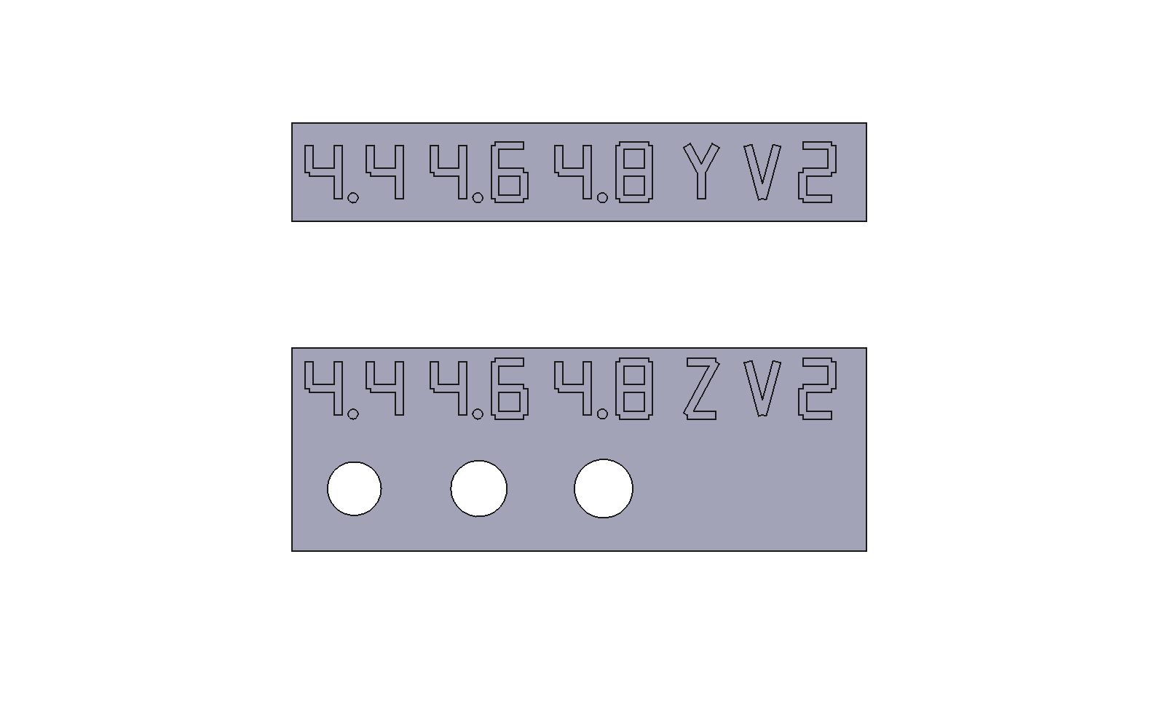
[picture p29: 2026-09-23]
models/auticko-silovy-prevod-25/kalibrace-4-v2/popisky.png

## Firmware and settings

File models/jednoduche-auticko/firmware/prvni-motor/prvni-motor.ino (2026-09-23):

#include <WiFiS3.h>
#include <FspTimer.h>
#include <pwm.h>
#include <ctype.h>
#include <string.h>
#include <stdio.h>

// Obousměrný pohon se stejným výkonem; zachovaný uživatelem ověřený střed SG90.
const char BUILD_ID[] = "v3-reverse-v1";
constexpr uint8_t EN = 5, IN1 = 7, IN2 = 8, STEER_PIN = 9;
constexpr uint16_t STEER_CENTER_US=1575, STEER_OFFSET_US=300;
constexpr int8_t STEER_SIGN=1; // Ověřit směr s odpojeným táhlem; ±300 us není změřený úhel.
const char SSID[] = "Auticko-test", PASSWORD[] = "auticko123"; // Veřejné demo heslo.
WiFiServer server(80);
bool ready = false;
bool apConfigured=false, networkAttempted=false;
uint32_t networkCheckedAt=0, tokenSequence=0;
char motorToken[33]="", previousSessionToken[33]="", requestToken[33]="";
enum Request { INVALID, PAGE, SESSION, ARM, HOLD, STOP };
enum DriveState { IDLE, ARMED, RUNNING };
constexpr uint32_t LEASE_MS=500, ARM_WAIT_MS=3000, TIMER_TICK_MS=5;
constexpr uint32_t REVERSE_PAUSE_MS=250; // Electrical OFF interval, not proof of mechanical standstill.
PwmOut motorPwm(EN);
PwmOut steeringPwm(STEER_PIN);
FspTimer safetyTimer;
volatile bool pwmReady=false, servoReady=false, safetyReady=false;
volatile uint16_t steeringPulseUs=STEER_CENTER_US;
int8_t requestMotor=1;
volatile int8_t motorDirection=0, lastMotorDirection=0;
volatile uint32_t motorStoppedAt=0;
bool reversalRejected=false;
int8_t requestSteer=0;
volatile DriveState driveState=IDLE;
volatile uint16_t leaseTicks=0;
volatile uint32_t watchdogStops=0, armExpiries=0, runExpiries=0;
volatile uint8_t stopReason=0; // 0=start/local, 1=STOP, 2=ARM expiry, 3=RUN expiry, 4=network, 5=session, 6=PWM/RNG, 7=reversal
uint32_t diagnosticRequestLogAt=0;
uint32_t lastPress=0, requestPress=0, challengeIssuedAt=0;
char holdChallenge[33]="", requestChallenge[33]="";
Request readRequest(WiFiClient &client); // Explicitně kvůli Arduino generování prototypů.
bool setSteering(int8_t direction);

// UNO R4 WiFi Serial je UART přes ESP bridge: bool() vždy true, bez detekce monitoru.
// Krátký synchronní přenos při 115200; žádné čekání na monitor ani Serial.flush().
char diagnosticFirmware[24]="not-read";
uint8_t diagnosticIP[4]={0,0,0,0};
const char *diagnosticSetup="starting";
int diagnosticStatus=-1, diagnosticApStart=-1;
uint32_t diagnosticStatusAt=0, diagnosticSnapshotAt=0, diagnosticHttpAt=0;
uint32_t diagnosticStatusLogAt=0;
uint32_t diagnosticAccepted=0, diagnosticClosed=0;
bool diagnosticHttpSeen=false;
void diagnosticEvent(const char *event, long value) {
  char line[96];
  const int n=snprintf(line,sizeof(line),"DIAG %lu %s %ld\n",millis(),event,value);
  if (n>0 && n<int(sizeof(line))) Serial.write(reinterpret_cast<uint8_t *>(line),size_t(n));
}
void diagnosticPoll() {
  bool requested=false;
  for (uint8_t i=0;i<8 && Serial.available()>0;++i) if (Serial.read()=='?') requested=true;
  const uint32_t now=millis(), elapsed=uint32_t(now-diagnosticSnapshotAt);
  if (elapsed<5000 && !(requested && elapsed>=1000)) return;
  diagnosticSnapshotAt=now;
  char line[160];
  const int state=int(driveState);
  int detail=snprintf(line,sizeof(line),"DIAG build=%s safety=%d drive=%d ENread=%d IN1=%d IN2=%d watchdog=%lu\n",
    BUILD_ID,int(safetyReady),state,int(digitalRead(EN)),int(digitalRead(IN1)),int(digitalRead(IN2)),
    static_cast<unsigned long>(watchdogStops));
  if(detail>0 && detail<int(sizeof(line)))Serial.write(reinterpret_cast<uint8_t *>(line),size_t(detail));
  detail=snprintf(line,sizeof(line),"DIAG steeringReady=%d steeringUs=%u neutralUs=%u rangeUs=%u\n",
    int(servoReady),unsigned(steeringPulseUs),unsigned(STEER_CENTER_US),unsigned(STEER_OFFSET_US));
  if(detail>0 && detail<int(sizeof(line)))Serial.write(reinterpret_cast<uint8_t *>(line),size_t(detail));
  int counters=snprintf(line,sizeof(line),"DIAG armExpired=%lu runExpired=%lu stopReason=%u leaseMs=%u challengeAgeMs=%lu\n",
    static_cast<unsigned long>(armExpiries),static_cast<unsigned long>(runExpiries),unsigned(stopReason),
    unsigned(leaseTicks*TIMER_TICK_MS),static_cast<unsigned long>(uint32_t(millis()-challengeIssuedAt)));
  if(counters>0 && counters<int(sizeof(line)))Serial.write(reinterpret_cast<uint8_t *>(line),size_t(counters));
  int n=snprintf(line,sizeof(line),"DIAG %lu boot=%s fw=%s ip=%u.%u.%u.%u\n",
    millis(),diagnosticSetup,diagnosticFirmware,unsigned(diagnosticIP[0]),unsigned(diagnosticIP[1]),
    unsigned(diagnosticIP[2]),unsigned(diagnosticIP[3]));
  if (n>0 && n<int(sizeof(line))) Serial.write(reinterpret_cast<uint8_t *>(line),size_t(n));
  n=snprintf(line,sizeof(line),"DIAG ready=%d server=%d APstart=%d statusLast=%d ageMs=%lu HTTP=%lu closed=%lu\n",
    int(ready),int(bool(server)),diagnosticApStart,diagnosticStatus,
    static_cast<unsigned long>(uint32_t(now-diagnosticStatusAt)),
    static_cast<unsigned long>(diagnosticAccepted),static_cast<unsigned long>(diagnosticClosed));
  if (n>0 && n<int(sizeof(line))) Serial.write(reinterpret_cast<uint8_t *>(line),size_t(n));
}
const char HTML[] = R"HTML(<!doctype html><html lang="cs"><meta charset="utf-8">
<meta name="viewport" content="width=device-width,initial-scale=1"><title>Ovládání autíčka</title>
<style>
*{box-sizing:border-box}body{font:17px system-ui;max-width:32rem;margin:0 auto;padding:1.25rem;line-height:1.5;color:#172a32;background:#f5f7f8}
h1{font-size:1.7rem;margin:.25rem 0}.label{color:#596b75;font-size:.85rem;margin:0 0 1.5rem}p{margin:.8rem 0}
button{font:inherit;font-weight:600;min-height:76px;padding:1rem .6rem;border:1px solid #bac9cf;border-radius:12px;color:inherit;background:#fff;cursor:pointer;touch-action:none;user-select:none;-webkit-user-select:none}
button:focus-visible{outline:3px solid #167bcb;outline-offset:3px}button:disabled{cursor:wait;opacity:.6}
.drive{display:grid;grid-template-columns:1fr 1fr;gap:.6rem;margin:.7rem 0 1.25rem}.drive button{background:#174d3a;color:#fff;border-color:#174d3a;min-height:108px}
.drive button[data-running="true"]{background:#267a55}.steering{display:grid;grid-template-columns:1fr 1fr 1fr;gap:.6rem}
button[data-active="true"]{background:#dceeff;border-color:#167bcb}.hint{font-size:.88rem;color:#50636e}
#result{background:#fff;border:1px solid #dce3e7;border-radius:12px;padding:1rem;min-height:82px;margin-top:1.4rem}
.warning{font-size:.83rem;padding-top:1rem;border-top:1px solid #dce3e7;color:#53636c}
</style>
<h1>Ovládání autíčka</h1><p class="label">Pohon vpřed a vzad · řízení SG90</p>
<p>Drž pro jízdu. Druhým prstem můžeš současně zatáčet.</p>
<div class="drive" role="group" aria-label="Pohon">
<button id="drive" type="button">↑<br>Držet pro jízdu vpřed</button>
<button id="reverse" type="button">↓<br>Držet pro couvání</button>
</div>
<div class="steering" role="group" aria-label="Řízení">
<button id="left" type="button" aria-label="Držet doleva">←<br>Doleva</button>
<button id="center" type="button">Rovně</button>
<button id="right" type="button" aria-label="Držet doprava">→<br>Doprava</button>
</div>
<p class="hint">Doleva a doprava drž. Puštěním směru se řízení vrátí rovně. Samotné řízení motor nespustí.</p>
<p class="hint">Před změnou směru pohon pusť. Při rychlém přepnutí nebo držení obou směrů se vypne; pusť ovladače a stiskni znovu. Kola mohou ještě dobíhat.</p>
<p id="result" role="status" aria-live="polite">Připraveno. Motor je vypnutý, řízení rovně.</p>
<p class="warning">Zkušební malý rozsah řízení. Po zapnutí servo dostane povel na střed; první nastavení proveď bez připojeného táhla. Při výpadku se pohon vypne a řízení vrátí na střed. Ztracený povel může znamenat prodlevu až 1 s; kola mohou dobíhat.</p><script>
const button=document.getElementById('drive'), result=document.getElementById('result');
const controls={drive:button,reverse:document.getElementById('reverse'),left:document.getElementById('left'),right:document.getElementById('right')};
const centerButton=document.getElementById('center');
const owners={drive:null,reverse:null,left:null,right:null}, active={drive:false,reverse:false,left:false,right:false};
const contacts=Object.fromEntries(Object.keys(owners).map(name=>[name,new Set()]));
let token='@TOKEN@', sessionNeeded=false;
let press=0, held=false, generation=0, timer=null, pending=null, stopping=false, nonce=null, dirty=false;
let rearmRequired=false;
const headers=(id,challenge)=>({'X-Motor-Control':'1','X-Motor-Token':token,'X-Motor-Press':String(id),
  ...(challenge?{'X-Motor-Challenge':challenge}:{})});
const intent=()=>({motor:active.drive?1:active.reverse?-1:0,steer:active.left===active.right?'center':active.left?'left':'right'});
const anyActive=()=>Object.values(active).some(Boolean);
function paint(){for(const [name,control] of Object.entries(controls))control.dataset.active=String(active[name]);}
function disable(value){for(const control of [...Object.values(controls),centerButton])control.disabled=value;}
async function command(path,id,challenge,state) {
  const controller=new AbortController(); pending=controller;
  const deadline=setTimeout(()=>controller.abort(),1200);
  try {
    const fields=path==='/session'?{'X-Motor-Control':'1','X-Motor-Token':token}:headers(id,challenge);
    if(state)Object.assign(fields,{'X-Control-Motor':String(state.motor),'X-Control-Steer':state.steer});
    const reply=await fetch(path,{method:'POST',headers:fields,body:'',cache:'no-store',signal:controller.signal});
    const text=await reply.text();if(!reply.ok)throw new Error('request');return text;
  } finally {clearTimeout(deadline);if(pending===controller)pending=null;}
}
function stop(message='Pohon vypnutý, řízení rovně. Pro další jízdu stiskni znovu.',failed=false,force=false) {
  if((!held && !force) || stopping)return;
  held=false;generation++;clearTimeout(timer);timer=null;nonce=null;
  for(const name of Object.keys(active))active[name]=false;paint();
  if(pending)pending.abort();if(failed)sessionNeeded=true;
  // Retain physical owners on error: a still-held touch/key cannot restart itself.
  button.dataset.running=controls.reverse.dataset.running='false';disable(true);stopping=true;result.textContent='Zastavuji a vracím řízení rovně…';
  if(force && press===0)press=1;
  const controller=new AbortController(), deadline=setTimeout(()=>controller.abort(),1500);
  fetch('/stop',{method:'POST',headers:headers(press),body:'',cache:'no-store',keepalive:true,signal:controller.signal})
    .then(async reply=>{if(!reply.ok || await reply.text()!=='STOP_OK')throw new Error();result.textContent=message;})
    .catch(()=>{sessionNeeded=true;result.textContent='Spojení přerušeno. Časovač vypne pohon a vrátí řízení. Pusť ovladače a stiskni znovu.';})
    .finally(()=>{clearTimeout(deadline);stopping=false;disable(false);});
}
async function start() {
  if(held || stopping || button.disabled || document.hidden || !anyActive())return;
  held=true;nonce=null;const gen=++generation;result.textContent='Připravuji ovládání…';
  try {
    if(sessionNeeded) {
      const session=await command('/session');
      if(!held || gen!==generation)return;
      if(!/^SESSION_OK:[0-9a-f]{32}$/.test(session))throw new Error();
      token=session.slice(11);press=0;sessionNeeded=false;
    }
    const id=++press,armed=await command('/arm',id);
    if(!held || gen!==generation)return;
    if(!/^ARM_OK:[0-9a-f]{32}$/.test(armed))throw new Error();
    nonce=armed.slice(7);await heartbeat(id,gen);
  } catch(_){if(held && gen===generation)stop(undefined,true);}
}
async function heartbeat(id,gen) {
  if(!held || gen!==generation || !nonce || pending)return;
  const challenge=nonce,state=intent();nonce=null;dirty=false;
  try {
    const reply=await command('/hold',id,challenge,state);
    if(!held || gen!==generation)return;
    if(reply==='HOLD_REARM'){rearmRequired=true;stop('Změna směru: pusť ovladače a stiskni znovu.');return;}
    if(!/^HOLD_OK:[0-9a-f]{32}$/.test(reply))throw new Error();
    nonce=reply.slice(8);button.dataset.running=String(state.motor===1);controls.reverse.dataset.running=String(state.motor===-1);
    result.textContent=(state.motor===1?'Pohon vpřed':state.motor===-1?'Pohon vzad':'Motor vypnutý')+' · '+({left:'řízení doleva',center:'řízení rovně',right:'řízení doprava'}[state.steer])+'.';
    timer=setTimeout(()=>{timer=null;heartbeat(id,gen);},dirty?0:20);
  } catch(_){if(held && gen===generation)stop(undefined,true);}
}
function changed() {
  paint();if(!anyActive()){stop();return;}
  if(!held){start();return;}
  dirty=true;
  if(nonce && !pending){clearTimeout(timer);timer=null;heartbeat(press,generation);}
}
function begin(name,owner) {
  if(document.hidden || contacts[name].has(owner))return;
  contacts[name].add(owner);
  // Track rejected contacts too: they must be released, never silently forgotten.
  if(rearmRequired || stopping || controls[name].disabled){rearmRequired=true;return;}
  if(owners[name]!==null)return; // No transfer to a second contact on the same button.
  owners[name]=owner;
  if((name==='drive' && contacts.reverse.size) || (name==='reverse' && contacts.drive.size)){
    rearmRequired=true;stop('Oba směry pohonu: pusť ovladače a stiskni znovu.',false,true);return;
  }
  active[name]=true;changed();
}
function release(owner) {
  let found=false;
  for(const heldContacts of Object.values(contacts))if(heldContacts.delete(owner))found=true;
  for(const name of Object.keys(owners))if(owners[name]===owner){owners[name]=null;active[name]=false;found=true;}
  if(!Object.values(contacts).some(value=>value.size))rearmRequired=false;
  if(found)changed();
}
for(const [name,control] of Object.entries(controls)) {
  control.addEventListener('pointerdown',event=>{
    if(event.button!==0 || (event.pointerType!=='touch' && !event.isPrimary) || document.hidden)return;
    event.preventDefault();control.setPointerCapture(event.pointerId);begin(name,'p'+event.pointerId);
  });
  control.addEventListener('lostpointercapture',event=>release('p'+event.pointerId));
  control.addEventListener('contextmenu',event=>event.preventDefault());
  control.addEventListener('keydown',event=>{
    if(event.code!=='Space' && event.code!=='Enter')return;
    event.preventDefault();if(!event.repeat)begin(name,'k'+event.code);
  });
}
window.addEventListener('pointerup',event=>release('p'+event.pointerId));
// Cancellation may signal a system gesture: invalidate both controls together.
window.addEventListener('pointercancel',event=>{stop();release('p'+event.pointerId);});
window.addEventListener('keydown',event=>{
  const name={ArrowUp:'drive',ArrowDown:'reverse',ArrowLeft:'left',ArrowRight:'right'}[event.code];
  if(name){event.preventDefault();if(!event.repeat)begin(name,'k'+event.code);}
});
window.addEventListener('keyup',event=>{if(['Space','Enter','ArrowUp','ArrowDown','ArrowLeft','ArrowRight'].includes(event.code)){event.preventDefault();release('k'+event.code);}});
centerButton.addEventListener('click',()=>{
  active.left=active.right=false;paint();
  if(anyActive())changed();else stop('Motor vypnutý, řízení rovně.',false,true);
});
function leave(){stop();for(const name of Object.keys(owners)){owners[name]=null;contacts[name].clear();}rearmRequired=false;}
window.addEventListener('blur',leave);window.addEventListener('pagehide',leave);
window.addEventListener('offline',()=>stop(undefined,true));
document.addEventListener('visibilitychange',()=>{if(document.hidden)leave();});
</script></html>)HTML";

// Volat jen v ISR nebo krátké kritické sekci. PWM je předem inicializované:
// žádná alokace, modem, čekání ani Serial. Směrové GPIO jdou LOW i při chybě PWM.
void motorOutputsOff() {
  if (pwmReady && !motorPwm.pulse_perc(0.0f)) {
    // Fail closed if the PWM peripheral ever refuses the OFF update.
    pinMode(EN,OUTPUT); digitalWrite(EN,LOW); pwmReady=false; safetyReady=false;
  }
  digitalWrite(IN1,LOW); digitalWrite(IN2,LOW); digitalWrite(LED_BUILTIN,LOW);
  if(motorDirection!=0){lastMotorDirection=motorDirection;motorDirection=0;motorStoppedAt=millis();}
}
uint32_t reversePauseRemaining() {
  const uint32_t elapsed=uint32_t(millis()-motorStoppedAt);
  return motorDirection==0 && lastMotorDirection!=0 && elapsed<REVERSE_PAUSE_MS ? REVERSE_PAUSE_MS-elapsed : 0;
}
// Called only inside the HOLD critical section. No timer or loop restarts motion.
bool setMotorDirection(int8_t direction) {
  if(direction==0){motorOutputsOff();return safetyReady;}
  if(motorDirection!=0 && motorDirection!=direction)motorOutputsOff();
  if(!safetyReady)return false;
  if(motorDirection==0 && lastMotorDirection!=0 && direction!=lastMotorDirection && reversePauseRemaining()){
    reversalRejected=true;return false;
  }
  digitalWrite(IN1,direction>0?HIGH:LOW);digitalWrite(IN2,direction<0?HIGH:LOW);
  if(!motorPwm.pulse_perc(128.0f*100.0f/255.0f))return false;
  motorDirection=direction;digitalWrite(LED_BUILTIN,HIGH);return true;
}
bool setSteering(int8_t direction) {
  if (!servoReady || direction < -1 || direction > 1) return false;
  const uint16_t pulse=STEER_CENTER_US + STEER_SIGN*int(direction)*STEER_OFFSET_US;
  if (!steeringPwm.pulse_perc(float(pulse)/200.0f)) {
    pinMode(STEER_PIN,OUTPUT); digitalWrite(STEER_PIN,LOW);
    servoReady=false; safetyReady=false; return false;
  }
  steeringPulseUs=pulse; return true;
}
void outputsOff() {
  motorOutputsOff();
  // Hardware50Hz PWM keeps producing the neutral pulse even if WiFi blocks.
  // A failed peripheral update disables all motion; LOW cannot promise centering.
  if (servoReady && !setSteering(0)) stopReason=6;
}
void motorStop() {
  noInterrupts(); driveState=IDLE; leaseTicks=0; outputsOff(); interrupts();
  holdChallenge[0]='\0';
}
void safetyTick(timer_callback_args_t *) {
  if (driveState!=IDLE && leaseTicks>0 && --leaseTicks==0) {
    if(driveState==ARMED){++armExpiries;stopReason=2;}else{++runExpiries;stopReason=3;}
    driveState=IDLE; outputsOff(); ++watchdogStops;
  }
}
bool initializeSafety() {
  // Reserve the PWM timer before asking for a separate, genuinely free timer.
  pwmReady=motorPwm.begin(490.0f,0.0f);
  if (!pwmReady) {pinMode(EN,OUTPUT); digitalWrite(EN,LOW); return false;}
  // Reserve D9 PWM too before allocating the independent5ms safety timer.
  // Startup commands the configured center; first set up without linkage.
  servoReady=steeringPwm.begin(50.0f,float(STEER_CENTER_US)/200.0f);
  if (!servoReady || !setSteering(0)) {
    pinMode(STEER_PIN,OUTPUT); digitalWrite(STEER_PIN,LOW); servoReady=false; return false;
  }
  uint8_t type=GPT_TIMER;
  const int8_t channel=FspTimer::get_available_timer(type);
  return channel>=0 && safetyTimer.begin(TIMER_MODE_PERIODIC,type,uint8_t(channel),
    1000.0f/TIMER_TICK_MS,0.0f,safetyTick) && safetyTimer.setup_overflow_irq(2) &&
    safetyTimer.open() && safetyTimer.start();
}
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
void loop() {
  diagnosticPoll();
  const uint32_t requestStarted=millis();
  if (!networkReady()) { motorStop(); delay(1); return; }
  WiFiClient client=server.available(); if (!client) {delay(1);return;}
  ++diagnosticAccepted;
  const Request request=readRequest(client);
  const uint32_t receivedAt=millis(), challengeAge=uint32_t(receivedAt-challengeIssuedAt);
  const int before=int(driveState);
  // No additional blocking modem call between validation and a lease grant.
  // networkReady() ran before reception; its delay is included below.
  bool ok=false;
  char reply[48]="Neplatny nebo stary pozadavek.";
  if (request==PAGE) respondPage(client);
  else if(request==SESSION) {
    // Only a new physical press after failure asks for this. It cannot move a motor.
    if(motorToken[0] && previousSessionToken[0] && !strcmp(requestToken,previousSessionToken)) {
      ok=true; // Lost response retry: reveal the same session, never stop a newer drive.
    } else if(!motorToken[0] || !strcmp(requestToken,motorToken)) {
      motorStop();stopReason=5;lastPress=0;
      memcpy(previousSessionToken,requestToken,33);ok=mintMotorToken();
    }
    if(ok)snprintf(reply,sizeof(reply),"SESSION_OK:%s",motorToken);
    respond(client,ok,"text/plain; charset=utf-8",reply);
  }
  else {
    const bool fresh=uint32_t(millis()-requestStarted)<HTTP_READ_TIMEOUT_MS;
    if (request==STOP) { applyStop(requestPress); ok=true; snprintf(reply,sizeof(reply),"STOP_OK"); }
    else if (fresh && request==ARM && applyArm(requestPress)) {
      ok=true;snprintf(reply,sizeof(reply),"ARM_OK:%s",holdChallenge);
    } else if (fresh && request==HOLD) {
      if(applyHold(requestPress,requestChallenge,requestMotor,requestSteer)){
        ok=true;snprintf(reply,sizeof(reply),"HOLD_OK:%s",holdChallenge);
      } else if(reversalRejected){
        // No next nonce: this press is latched OFF, even after the pause expires.
        ok=true;snprintf(reply,sizeof(reply),"HOLD_REARM");
      }
    } // Invalid/obsolete requests cannot renew a lease or stop a newer press.
    respond(client,ok,"text/plain; charset=utf-8",reply);
  }
  client.stop(); ++diagnosticClosed;
  if(request!=HOLD || !ok || uint32_t(millis()-diagnosticRequestLogAt)>=1000) {
    diagnosticRequestLogAt=millis();
    const char *kind=request==PAGE?"PAGE":request==SESSION?"SESSION":request==ARM?"ARM":request==HOLD?"HOLD":request==STOP?"STOP":"INVALID";
    char line[160];
    const int n=snprintf(line,sizeof(line),"HTTP %s ok=%d press=%lu rxMs=%lu replyMs=%lu challengeAgeMs=%lu phase=%d->%d reason=%u\n",
      kind,int(ok),static_cast<unsigned long>(requestPress),static_cast<unsigned long>(receivedAt-requestStarted),
      static_cast<unsigned long>(uint32_t(millis()-receivedAt)),static_cast<unsigned long>(challengeAge),before,int(driveState),unsigned(stopReason));
    if(n>0&&n<int(sizeof(line)))Serial.write(reinterpret_cast<uint8_t *>(line),size_t(n));
  }
}

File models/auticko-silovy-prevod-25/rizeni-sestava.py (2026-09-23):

def rotatez(a,angle):
    a.Placement.Rotation=App.Rotation(App.Vector(0,0,1),0);a.setExpression('Placement.Rotation.Angle',angle)
kin=[]
for side,tag in [(-1,'L'),(1,'R')]:
    y=f'{side} * '+s('HalfTrack')
    caplink=link('AssemblyForkCap'+tag,cap,s('KingpinX'),y,38,App.Rotation(App.Vector(0,0,1),0 if side==1 else 180))
    link('AssemblyKingpin'+tag,king,s('KingpinX'),y,45.3,App.Rotation(App.Vector(1,0,0),180))
    link('AssemblyKingClip'+tag,gearclip,s('KingpinX'),y,11.6,App.Rotation(App.Vector(0,0,1),-side*90))
    a=link('AssemblyKnuckle'+tag,knuckles[side],s('KingpinX'),y,28);rotatez(a,s('WheelAngle'));kin.append(a)
    # Transform wheel plane around Z through kingpin; quaternion via attachment wrapper group.
    group=D.addObject('App::Part','WheelCarrier'+tag);pos(group,s('KingpinX'),y,28);rotatez(group,s('WheelAngle'));assembly.addObject(group)
    wheel=link('AssemblySteeringWheel'+tag,frontwheel,'-'+s('Trail'),side*21,0,rxn if side==-1 else rxp);assembly.removeObject(wheel);group.addObject(wheel)
    wc=link('AssemblyWheelClip'+tag,gearclip,'-'+s('Trail'),side*21.4,0,rxn if side==1 else rxp);assembly.removeObject(wc);group.addObject(wc)
    kin+=[group]
    # Čep kloubu od horní příruby dolů; stejné dolní jištění Z39.6..40.9.
    long=side==-1;z=57.6 if long else 54.2
    jl=link('AssemblyJointPin'+tag,jointlong if long else jointshort,s('EndX'),y+' + '+s('Arm')+' * sin('+s('WheelAngle')+')',z,App.Rotation(App.Vector(1,0,0),180));kin.append(jl)
    cl=link('AssemblyJointClip'+tag,jointclip,s('EndX'),y+' + '+s('Arm')+' * sin('+s('WheelAngle')+')',43.6);kin.append(cl)
tiel=link('AssemblyTie',tie,s('EndX'),s('EndLeftY'),s('TieBottom'));kin.append(tiel)
dl=link('AssemblyDrag',drag,s('HornX'),s('HornY'),s('DragBottom'));rotatez(dl,s('DragAngle'));kin.append(dl)
hs=link('AssemblyHornSpacer',horn_spacer,s('HornX'),s('HornY'),50.2);kin.append(hs)
# Nominální reference SG90. Posun osy proti krabičce neznámý; explicitní parametr.
servo=cyl('ServoShaftReference',2.3,3.3,(s('ServoX'),0,s('ServoFloor')+' + '+s('ServoHeight')))
body=box('ServoBodyReference',(s('ServoWidth'),s('ServoLength'),s('ServoHeight')),(s('ServoX')+' - '+s('ServoWidth')+'/2','-'+s('CaseAxisOffset'),s('ServoFloor')))
ears=box('ServoEarsReference',(s('ServoWidth'),32.3,3),(s('ServoX')+' - '+s('ServoWidth')+'/2','-'+s('CaseAxisOffset')+' - 4.8 mm',s('ServoFloor')+' + 17 mm'))
ref=fuse('ServoReference',[body,servo,ears]);ref.Label='SG90 — nominální reference, fit těla/páčky NEOVĚŘEN';assembly.addObject(ref)
# Horn je pouze návrhová prostorová obálka, netiskne se a nenahrazuje originální spline.
hraw=fuse('HornReferenceMaterial',[cyl('HornHubReference',3.5,s('HornThickness')),box('HornArmReference',(s('HornRadius'),4,s('HornThickness')),('-'+s('HornRadius'),-2,0)),cyl('HornEyeReference',3,s('HornThickness'),('-'+s('HornRadius'),0,0))])
# Původní malý otvor není základem nového spoje; jeho průměr není známý.
horn=D.addObject('App::Link','AssemblyHornReference');horn.setLink(hraw);pos(horn,s('ServoX'),0,s('HornBottom'));assembly.addObject(horn);rotatez(horn,s('ServoAngle'));horn.Label='ORIGINÁLNÍ páčka: r15 potvrzen, ostatní obálka návrhová';kin.append(horn)

for tag,part in [('Tray',horn_tray),('Lid',horn_lid)]:
    a=link('AssemblyHorn'+tag,part,s('ServoX'),0,0);rotatez(a,s('ServoAngle'));kin.append(a)
# Příčný zamykací čep objímky se otáčí v pomocném nosiči spolu s původní páčkou.
hc=D.addObject('App::Part','HornLockCarrier');pos(hc,s('ServoX'),0,0);rotatez(hc,s('ServoAngle'));assembly.addObject(hc)
for name,part,y in [('Pin',horn_lock_pin,-12.2),('Clip',smallclip,10.4)]:
    a=link('AssemblyHornLock'+name,part,-21,y,46.5,ry);assembly.removeObject(a);hc.addObject(a)
kin.append(hc)
a=link('AssemblyHornPivotClip',gearclip,s('HornX'),s('HornY'),55.5);kin.append(a)
link('AssemblyServoCap',servo_cap,s('ServoX'),0,0)
for side in (-1,1):
    link('AssemblyServoMountPin'+str(side+2),servo_mount_pin,s('ServoX')+f' + {side*10} mm',-18.4,37.4,ry)
    link('AssemblyServoMountClip'+str(side+2),smallclip,s('ServoX')+f' + {side*10} mm',29.9,37.4,ry)
